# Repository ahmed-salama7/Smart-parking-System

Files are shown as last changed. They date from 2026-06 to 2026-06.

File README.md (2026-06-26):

# Smart Parking System

> An automated parking-management prototype that detects vehicles with FC-51 IR
> sensors at the entrance and exit and controls access through a servo gate,
> driven by a finite-state-machine firmware on an Arduino Uno. Live occupancy is
> shown on an LCD with traffic-light feedback.

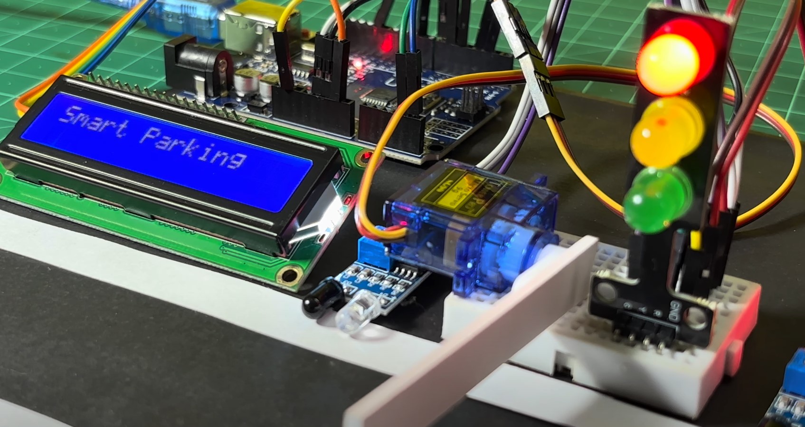
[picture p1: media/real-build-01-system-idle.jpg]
Smart Parking System — real build


---

## Problem

Conventional parking lots give drivers no live information about availability —
you enter, search, and often find the lot full only after wasting time and fuel.
This project demonstrates an automated, low-cost alternative: a system that
tracks occupancy in real time, controls access automatically, and shows drivers
the number of free spaces at a glance.

---

## How It Works

- **Two FC-51 IR sensors** detect vehicles at the entrance and the exit
  (active-LOW digital output — LOW when a car breaks the beam).
- The system **counts cars in and out against a 4-space capacity** — it tracks
  total occupancy rather than sensing each individual bay.
- A **finite state machine** in firmware manages the full gate cycle:
  `idle → car detected → check capacity → open → pass-through → close`.
- An **SG90 servo** drives the entry/exit barrier (0° closed, 90° open).
- A **16×2 I²C LCD** displays live status — free-slot count and OPEN / FULL.
- A **traffic-light LED module** gives instant visual feedback
  (green = enter, yellow = gate moving, red = full).

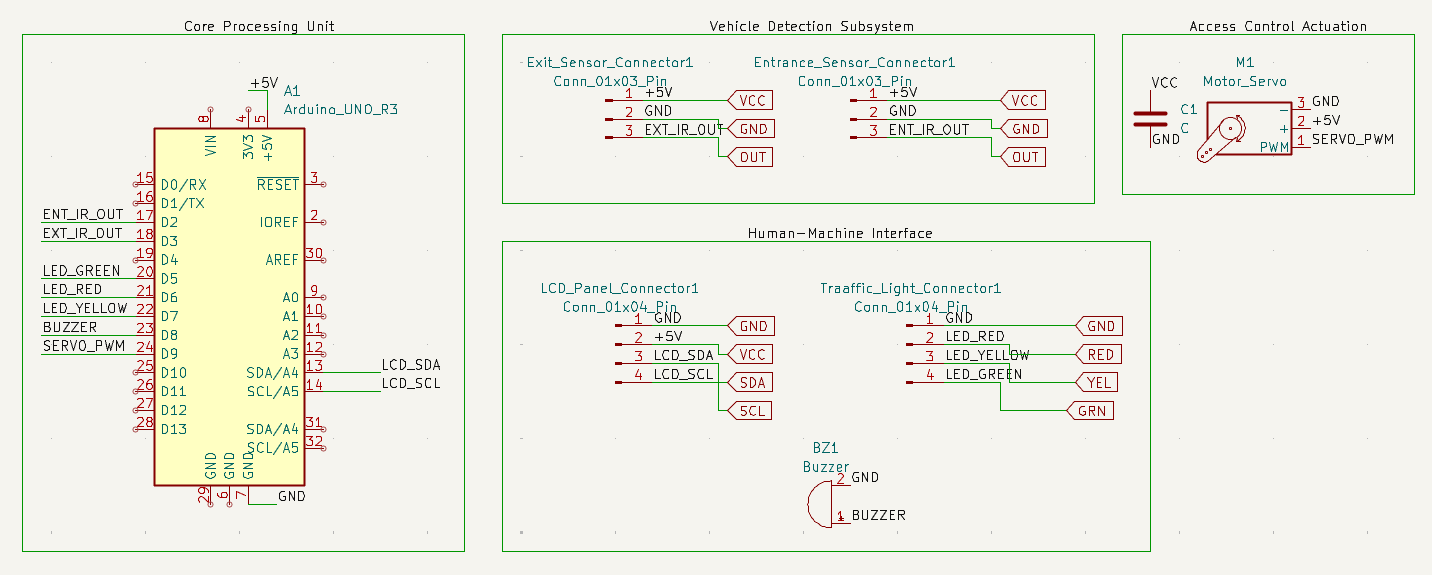
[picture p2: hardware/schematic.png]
System schematic

*System schematic, designed in KiCad.*

---

## Key Components

- **Microcontroller:** Arduino Uno R3 (ATmega328P)
- **Sensors:** FC-51 IR obstacle sensors ×2 (entrance + exit)
- **Actuator:** TowerPro SG90 micro servo (gate barrier)
- **Display:** 16×2 character LCD with PCF8574 I²C backpack
- **Indicators:** Traffic-light LED module (R/Y/G)
- **Custom PCB:** carrier shield designed in KiCad (see [`/hardware`](hardware/))

Full bill of materials: [`docs/SmartParking_BOM.xlsx`](docs/SmartParking_BOM.xlsx).
Engineering write-up: [`docs/DESIGN_NOTES.md`](docs/DESIGN_NOTES.md).

---

## Hardware Design

A custom carrier PCB was designed in KiCad to move the project off breadboard
wiring. The full project files (schematic, board, and project) are in
[`/hardware`](hardware/).

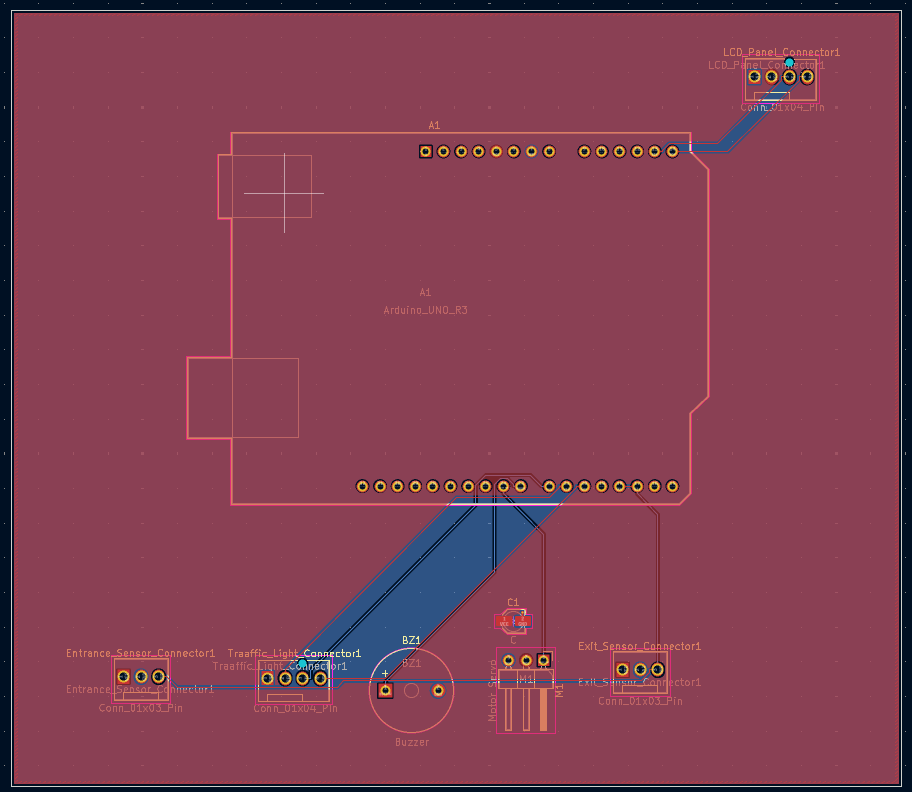
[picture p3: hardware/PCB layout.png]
PCB layout

*Custom PCB layout (KiCad).*

---

## Engineering Notes — From Simulation to Hardware

The control logic was first validated in a **Wokwi simulation**, then ported to
the physical board. That port was the most instructive part of the build:

- **Different sensors in simulation vs hardware.** Wokwi doesn't provide the
  FC-51 IR module, so the simulation uses **HC-SR04 ultrasonic** sensors while
  the real board ([`firmware/arduino_smart_parking_system_fc51.ino`](firmware/arduino_smart_parking_system_fc51.ino))
  uses **FC-51 IR**. The two detect vehicles differently as a result: the
  simulation reads an ultrasonic *distance* and compares it against a threshold,
  whereas the real board reads the FC-51's *digital beam-break* output directly.
- **Debouncing the IR input.** A raw IR module can blip on ambient light or a
  passing hand, so the firmware only accepts a vehicle after several consecutive
  "detected" reads — rejecting single-frame false triggers.
- **A gate safety timeout.** If a vehicle stalls in the beam or a sensor sticks
  on, the gate force-closes after a fixed timeout instead of hanging open and
  freezing the whole system.

---

## The System in Action

The physical prototype running a complete parking cycle — from an empty lot,
through vehicles entering, to a full lot denying access:

| | | |
|:--:|:--:|:--:|
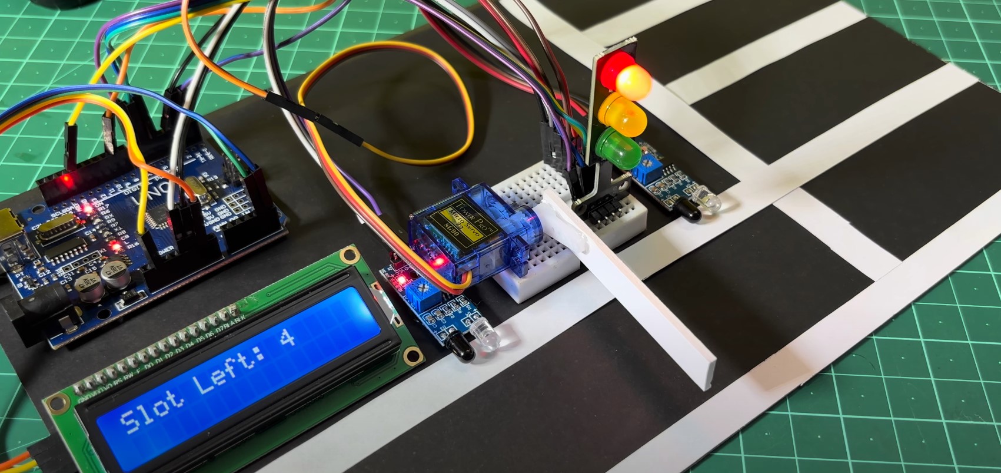
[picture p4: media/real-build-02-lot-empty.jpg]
Lot empty
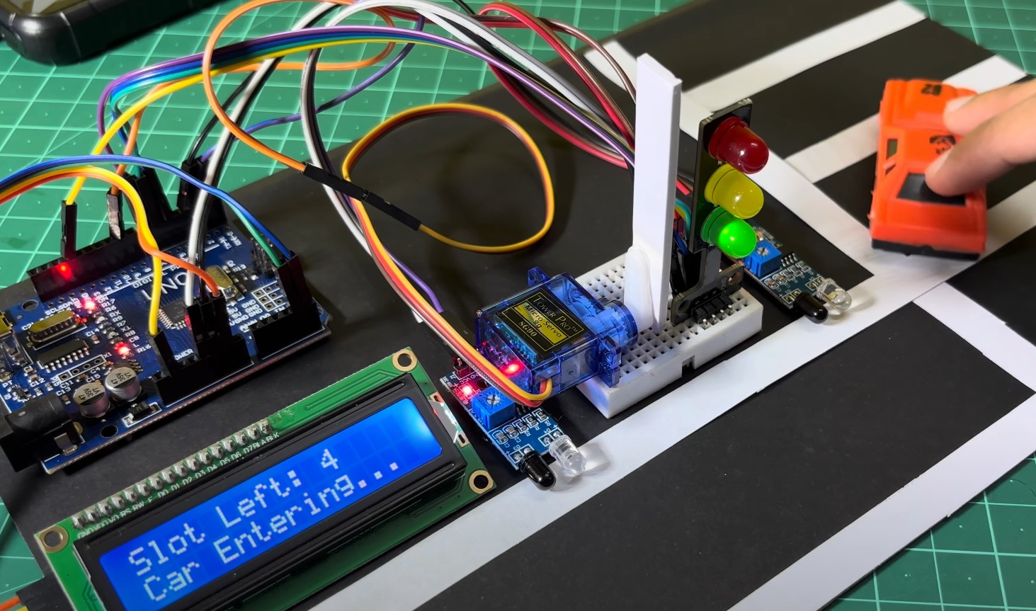
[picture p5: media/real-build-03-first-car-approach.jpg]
First car approaching
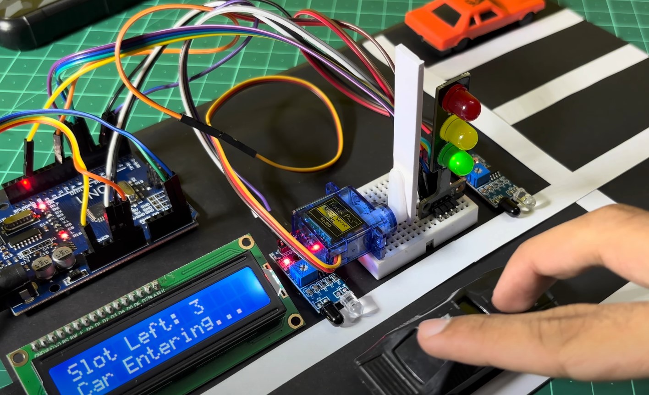
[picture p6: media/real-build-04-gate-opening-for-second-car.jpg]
Gate opening
|  |  |  |
| **Lot empty** — 4 slots free, gate down | **First car approaches**  | **Gate opens** — "Car entering..." |
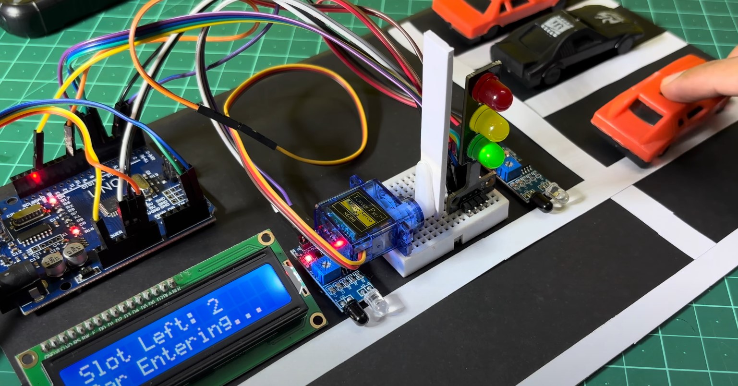
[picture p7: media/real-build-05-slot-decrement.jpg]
Slot decrement
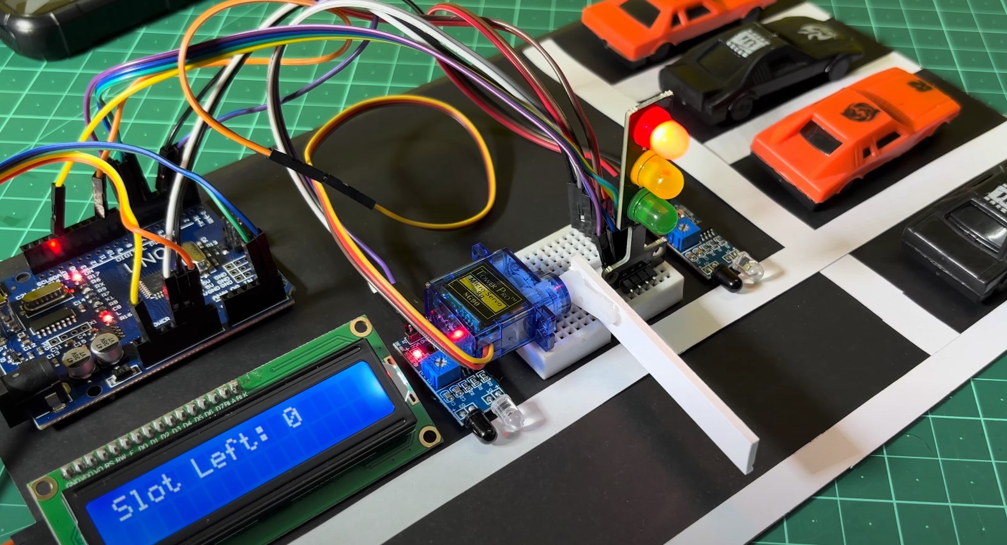
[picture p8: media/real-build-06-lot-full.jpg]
Lot full
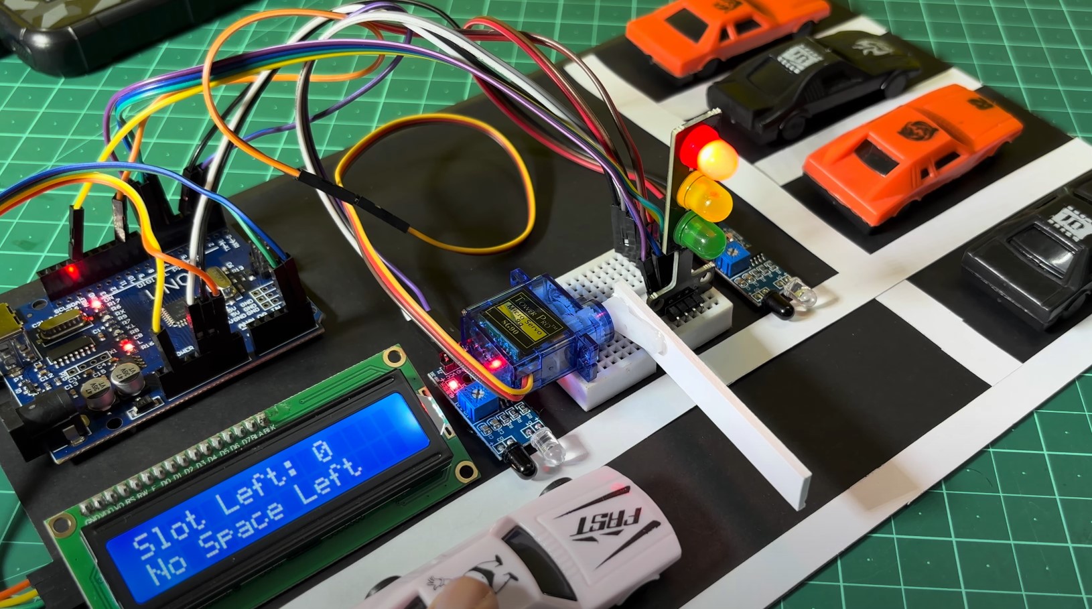
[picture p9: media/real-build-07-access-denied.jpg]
Access denied
|  |  |  |
| **Slot count drops** as cars are admitted | **Lot full** — 0 spaces available | **Access denied** — "No Space Left", red light |

---

## Simulation

The full control logic was validated in a Wokwi simulation before hardware
testing (sensor difference explained in *Engineering Notes* above).

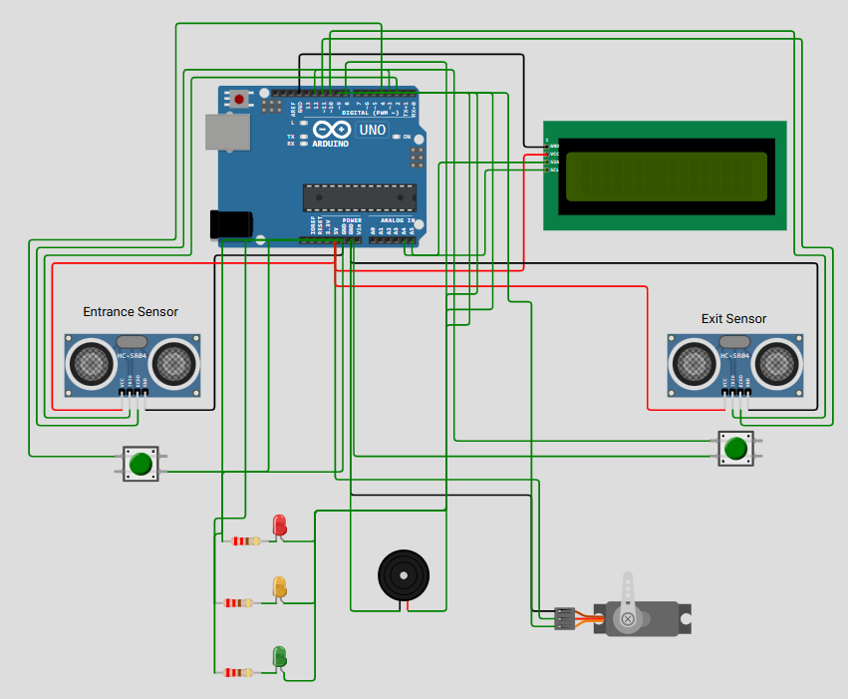
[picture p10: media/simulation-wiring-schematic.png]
Simulation wiring

*Wokwi simulation wiring (uses HC-SR04 in place of the FC-51 modules).*

Simulation demo

[▶️ Watch the full simulation video](media/simulation-behavioral-demo-video.mp4)

---

## Repository Structure

```
Smart-parking-System/
├── firmware/
│   └── arduino_smart_parking_system_fc51.ino   Real board (FC-51 IR)
├── hardware/
│   ├── Smart Parking System.kicad_sch          KiCad schematic
│   ├── Smart Parking System.kicad_pcb          KiCad board layout
│   ├── Smart Parking System.kicad_pro          KiCad project
│   ├── schematic.png                           Schematic export
│   └── PCB layout.png                          PCB layout export
├── docs/
│   ├── DESIGN_NOTES.md                         Engineering write-up
│   └── SmartParking_BOM.xlsx                    Bill of materials
├── media/                                      Real-build photos, sim video/GIF
└── README.md
```

---

## Status

Working hardware prototype, 2026.

<!-- [VERIFY] Optional metric: "Detection accuracy 100% (entrance) / 95% (exit)
over 20 trials each." Keep this ONLY if you actually ran and logged these
trials. If you didn't, delete this comment entirely. -->

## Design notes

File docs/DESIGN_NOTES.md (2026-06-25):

# Design Notes — Smart Parking System

Engineering design documentation for the Smart Parking System: an Arduino-based
parking-management prototype that detects vehicles with IR sensors, controls a
servo gate via a finite-state-machine firmware, and reports live occupancy on an
LCD with traffic-light and buzzer feedback.

---

## 1. Design Goals

The project set out to satisfy four requirements:

1. Detect vehicle presence at the entrance and exit in real time.
2. Automatically open or deny gate access depending on available capacity.
3. Display live parking status to drivers (free slots, OPEN / FULL).
4. Achieve all of the above on a low-cost (~$22) Arduino platform with reliable,
   repeatable operation.

The guiding principle throughout was **reliability over features** — a simpler
system that never miscounts is more valuable than a complex one that occasionally
fails.

---

## 2. System Architecture

The system is organised as a classic three-stage embedded pipeline:

```
INPUT                  PROCESSING                 OUTPUT
─────                  ──────────                 ──────
Entrance IR  ─┐                              ┌─►  Servo gate (SG90)
              ├─►   Arduino Uno (ATmega328P)  ├─►  16×2 LCD (I²C)
Exit IR     ─┘      • Debounced events        ├─►  Traffic LEDs (R/Y/G)
                    • Finite state machine     └─►  Buzzer
                    • Occupancy + capacity
```

The Arduino Uno acts as the edge controller. All modules share a single
regulated 5 V rail and a common ground.

---

## 3. Component Selection & Rationale

| Function | Part chosen | Why this part |
|---|---|---|
| Controller | Arduino Uno R3 (ATmega328P) | Deterministic, instant-on, no OS, ample I/O, lowest cost for the job |
| Vehicle detection | FC-51 IR obstacle sensor ×2 | Clean active-LOW digital output (onboard LM393 comparator), no distance math, cheap, fixed beam path suits a gate |
| Gate actuator | TowerPro SG90 servo | Sufficient torque for a light barrier, simple PWM control, very low cost |
| Display | 16×2 LCD + PCF8574 I²C backpack | I²C cuts pin usage from 16 lines to 2 (SDA/SCL), freeing GPIO |
| Status indicator | Traffic-light LED module | Common-cathode with onboard SMD resistors — drive directly from GPIO, no external parts |
| Audio feedback | Active piezo buzzer module | Simple `tone()` control for entry chime and full-lot alarm |

**Key decision — IR over ultrasonic:** the FC-51 modules output a clean digital
LOW/HIGH, so the microcontroller does no distance calculation, needs no averaging
filter, and has no echo-timeout risk. For a gate, where the detection point is
fixed and known, this is more robust and cheaper than ultrasonic ranging.

---

## 4. Firmware Design

The firmware is written in embedded C++ and structured as an **explicit finite
state machine** rather than ad-hoc conditional logic.

**States:** `IDLE`, `VEHICLE_ENTERING`, `VEHICLE_EXITING`, `LOT_FULL_WARN`.

**Control flow:** the controller idles while monitoring both sensors. On an
entrance trigger it checks capacity — if a slot is free it opens the gate and
increments the count; if the lot is full it denies access with the buzzer and a
"PARKING FULL" message. The exit path is symmetrical and decrements the count.
All paths return to `IDLE` after updating the display and LEDs.

**Three robustness measures were designed in deliberately:**

- **Debounce timer (300 ms).** Recorded with `millis()`, this rejects repeat
  triggers from a single slow-moving vehicle so one car is counted exactly once.
- **`constrain()` guard.** The occupancy count is clamped between 0 and total
  capacity, making it mathematically impossible to under- or over-count
  regardless of sensor behaviour.
- **Mutually-exclusive dispatch (`else-if`).** Entrance and exit events can never
  be processed in the same loop cycle, preventing race conditions.

**Code-quality practices:** all magic numbers are named constants, all LED state
is set through a single `setLEDs()` function (one source of truth), string
literals are stored in flash with the `F()` macro to save SRAM, and serial debug
output is provided throughout for diagnostics.

---

## 5. Engineering Challenge — Power Integrity

This was the most significant problem encountered, and the most instructive.

**Symptom.** When the servo moved to operate the gate, the LCD would glitch
mid-message and the Arduino would occasionally reset.

**Diagnosis.** The SG90 draws a sharp inrush current the instant it starts
moving. On the breadboard — with thin jumper wires and no local energy storage —
that current spike pulled the shared 5 V rail down far enough to brown out the
logic and reset the microcontroller. The fault correlated exactly with gate
movement, which identified the servo as the source.

**Solution.** A **470 µF electrolytic bulk capacitor** placed directly across the
5 V rail next to the servo. The capacitor acts as a local energy reservoir,
supplying the inrush current so the rest of the circuit sees a stable supply.
This was implemented properly on the PCB, alongside a ground pour on both copper
layers and a widened trace to the servo.

**Result.** Power-related glitches dropped from ~6 per 50 gate cycles to 0.

This is the textbook reason decoupling and bulk capacitors exist; encountering it
firsthand turned a theoretical rule into practical understanding.

---

## 6. PCB Design

The breadboard prototype was translated into a custom PCB using KiCad.

- **Form factor:** a two-layer Arduino carrier shield. Because every part is a
  pre-built module, the board is a carrier that breaks each Arduino pin out to a
  labelled connector rather than a component-level board.
- **Connectors:** pluggable headers / screw terminals for every module, so parts
  remain reusable and the board is repairable. None are soldered directly.
- **Power integrity:** ground pour on both layers, a widened 5 V trace to the
  servo, and the 470 µF bulk capacitor positioned at the servo connector.
- **Workflow:** schematic capture → footprint assignment → two-layer routing →
  DRC → 3D render for a final placement check before fabrication.

---

## 7. Validation & Results

Testing was treated as a structured activity with defined trials and recorded
numerical results.

| Metric | Result |
|---|---|
| Entrance sensor detection accuracy | 100% (20/20 trials) |
| Exit sensor detection accuracy | 95% (19/20 trials) |
| Rail glitches before bulk capacitor | 6 per 50 gate cycles |
| Rail glitches after bulk capacitor | 0 per 50 gate cycles |
| Full entry-cycle time | ~2.5 s (dominated by vehicle pass-through) |
| Total BOM cost (required parts) | ~$21.70 |

The exit sensor's 95% reflects occasional beam interference from the mounting
angle, correctable with a small physical adjustment.

---

## 8. Known Limitations & Future Work

**Current limitations:**

- Single-gate, single-zone prototype.
- Blocking `delay()` / wait-for-clear logic means the system focuses on one event
  at a time (acceptable for one gate, but not ideal at scale).
- The gate holds open indefinitely if a vehicle stalls in the beam — a safe
  failure mode, but not a timed one.

**Future work:**

- **IoT upgrade:** add an ESP8266 to stream live occupancy over Wi-Fi to an MQTT
  broker, with a mobile app showing drivers availability before arrival. This is
  a pure addition — no change to the existing firmware or hardware.
- **RFID access control** for authenticated entry.
- **Multi-level scaling:** replicate the state machine per gate, reporting to a
  central controller.
- **Fully non-blocking firmware:** replace remaining `delay()` calls with a
  `millis()`-based scheduler so both sensors stay responsive during gate motion.

---

## 9. Notes on the Simulation

The physical build used FC-51 IR sensors. The Wokwi simulation used **HC-SR04
ultrasonic sensors instead**, because the FC-51 module is not available in Wokwi.
This introduced fluctuating distance readings in simulation, handled with a
five-sample averaging filter and a validity check discarding readings above
200 cm. This filtering is a **simulation-only** concern — the real FC-51 modules
output a clean digital signal that needs no filtering. The simulation was used to
validate the control logic before hardware testing and as a reproducible,
shareable demonstration of the system's behaviour.

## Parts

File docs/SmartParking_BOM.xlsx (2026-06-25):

Smart Parking System — Bill of Materials
Arduino-based Smart Parking Management System · real-hardware build
Currency: USD ($) · Prices are indicative — replace with your supplier (e.g. Robotistan) quotes before final submission
Item | Category | Component / Part | Key Specification | Interface / Pin | Qty | Unit Price ($) | Line Total ($) | Required | Function / Notes
1 | Core Control | Arduino Uno R3 (ATmega328P) | 8-bit MCU board, 16 MHz, 14 digital I/O, 6 analog in | USB / host | 1 | $8.50 | $8.50 | Yes | Edge controller — runs the state machine, reads sensors, drives all actuators
2 | Input — Sensor | FC-51 IR Obstacle Sensor — Entrance | LM393 comparator, potentiometer-calibrated, active-LOW digital output | D2 (digital in) | 1 | $1.20 | $1.20 | Yes | Detects a vehicle breaking the beam at the entrance lane
3 | Input — Sensor | FC-51 IR Obstacle Sensor — Exit | LM393 comparator, potentiometer-calibrated, active-LOW digital output | D3 (digital in) | 1 | $1.20 | $1.20 | Yes | Detects a vehicle leaving at the exit lane
4 | Output — Actuator | TowerPro SG90 Micro Servo (9g) | Plastic-gear, 0°–90° travel, 4.8–6 V, hardware-PWM control | D9 (PWM) | 1 | $2.50 | $2.50 | Yes | Raises (90°) / lowers (0°) the physical gate arm
5 | Output — Display | 16x2 LCD + PCF8574 I2C Backpack | HD44780 16x2 char, I2C address 0x27, 2-wire interface | A4/SDA, A5/SCL | 1 | $4.00 | $4.00 | Yes | Shows live slot count and OPEN / FULL status
6 | Output — Indicator | Traffic-Light LED Module | Red/Yellow/Green, common cathode, onboard SMD current-limit resistors | D5, D6, D7 | 1 | $2.00 | $2.00 | Yes | Visual parking status (no VCC pin — common cathode)
7 | Output — Audio | Active Piezo Buzzer Module | Active piezo transducer, driven by tone() square wave | D8 (digital) | 1 | $0.80 | $0.80 | Yes | Entry confirmation chime and lot-full alarm
8 | Prototyping | Mini Breadboard (170 tie-points) | Solderless, 170 contact points, self-adhesive base | — | 1 | $1.50 | $1.50 | Yes | Local mounting node for the servo and traffic-light module
9 | Supporting (opt.) | Jumper Wires — Dupont set | M-M / M-F, 2.54 mm, assorted lengths | — | 1 | $2.00 | $2.00 | Optional | Interconnect between the Uno and modules
10 | Supporting (opt.) | USB Cable (A–B) | Standard printer-type cable | USB | 1 | $1.50 | $1.50 | Optional | Firmware upload and power to the Uno
 |  | TOTAL — required items |  |  |  |  | $21.70
 |  | TOTAL — including optional items |  |  |  |  | $25.20
 |  | Distinct line items / total units |  |  |  |  | 10 items / 10 units

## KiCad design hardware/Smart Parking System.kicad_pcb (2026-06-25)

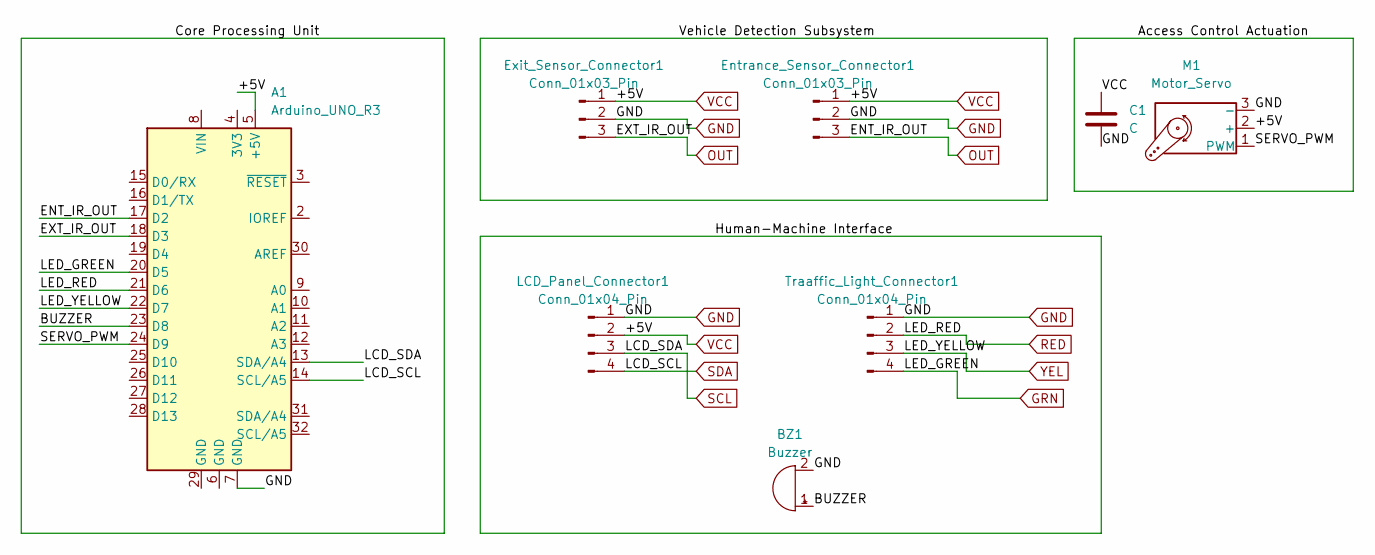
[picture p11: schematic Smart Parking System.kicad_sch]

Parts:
A1: Arduino_UNO_R3
BZ1: Buzzer; Buzzer_12x9.5RM7.6
C1: C; C_Elec_3x5.4
Entrance_Sensor_Connector1: Conn_01x03_Pin; FanPinHeader_1x03_P2.54mm_Vertical
Exit_Sensor_Connector1: Conn_01x03_Pin; FanPinHeader_1x03_P2.54mm_Vertical
LCD_Panel_Connector1: Conn_01x04_Pin; FanPinHeader_1x04_P2.54mm_Vertical
M1: Motor_Servo; PinHeader_1x03_P2.54mm_Horizontal
Traaffic_Light_Connector1: Conn_01x04_Pin; FanPinHeader_1x04_P2.54mm_Vertical

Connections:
/BUZZER: A1.23 (D8), BZ1.1 (+)
/SERVO_PWM: A1.24 (D9), M1.1 (PWM)
GND: A1.7 (GND), BZ1.2 (-), C1.2, Entrance_Sensor_Connector1.2, Exit_Sensor_Connector1.2, LCD_Panel_Connector1.1, M1.3 (-), Traaffic_Light_Connector1.1
GRN: A1.20 (D5), Traaffic_Light_Connector1.4
OUT: A1.17 (D2), A1.18 (D3), Entrance_Sensor_Connector1.3, Exit_Sensor_Connector1.3
RED: A1.21 (D6), Traaffic_Light_Connector1.2
SCL: A1.13 (SDA/A4), LCD_Panel_Connector1.3
SDA: A1.14 (SCL/A5), LCD_Panel_Connector1.4
VCC: A1.5 (+5V), C1.1, Entrance_Sensor_Connector1.1, Exit_Sensor_Connector1.1, LCD_Panel_Connector1.2, M1.2 (+)
YEL: A1.22 (D7), Traaffic_Light_Connector1.3

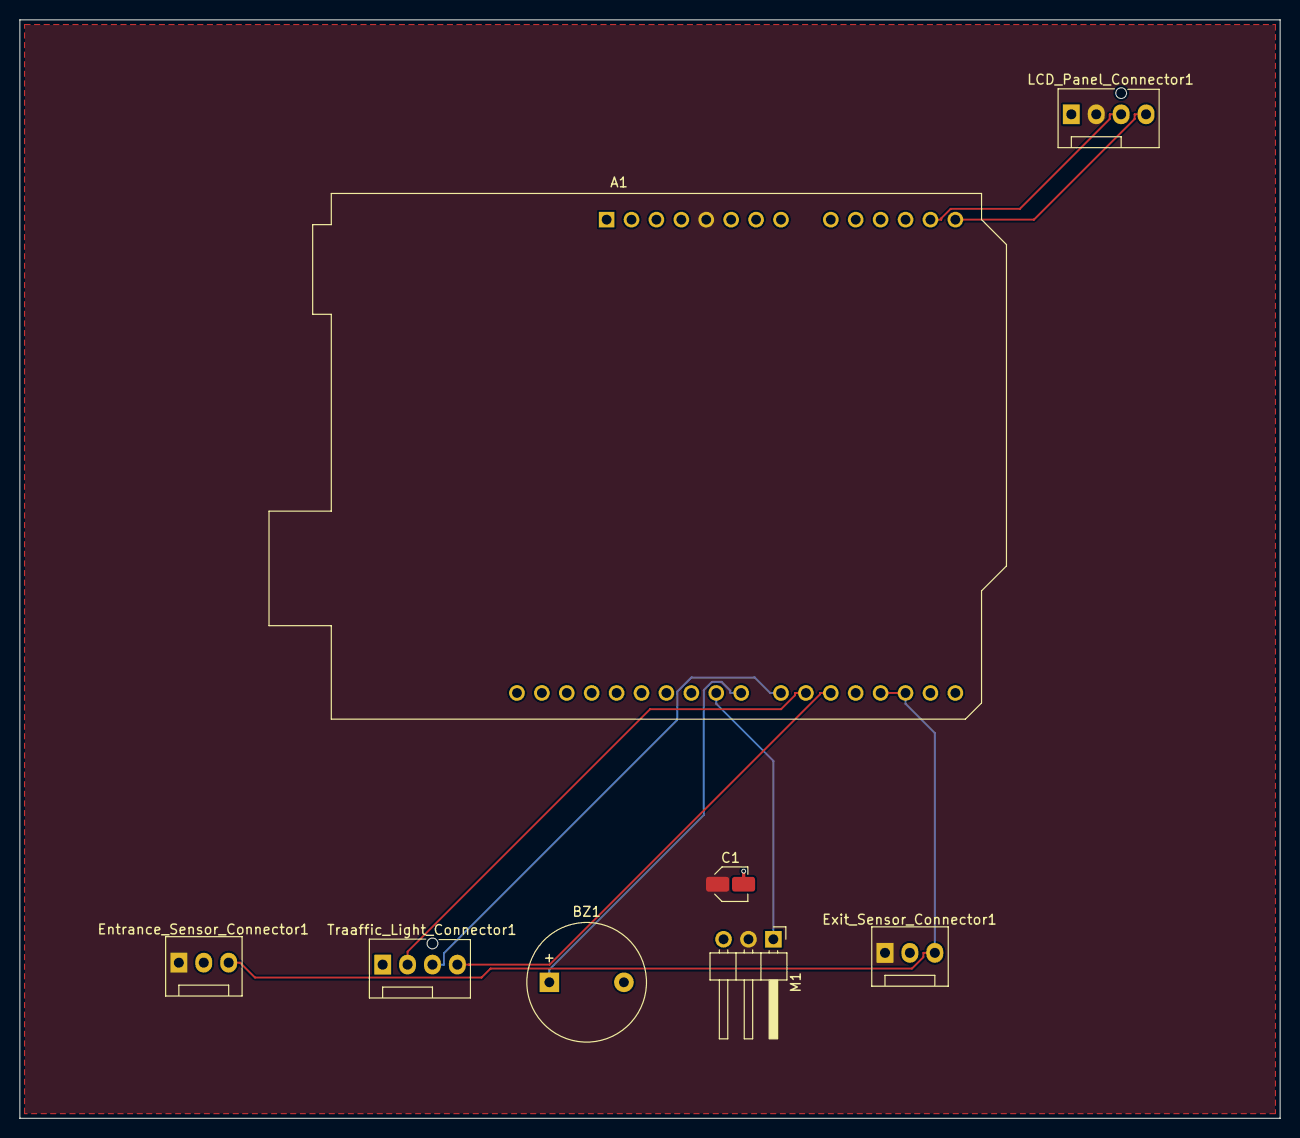
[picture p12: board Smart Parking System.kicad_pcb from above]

Board: 2 copper layers, 128.5 x 112.0 mm, 8 parts (0 on the bottom side), 10 nets.

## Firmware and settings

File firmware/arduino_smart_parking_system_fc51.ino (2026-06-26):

// =============================================================================
//  Smart Parking Management System  —  REAL BOARD (FC-51 IR sensors)
//
//  MCU      : Arduino Uno
//  Sensors  : 2x FC-51 IR obstacle sensors  (entrance + exit, active-LOW)
//  Actuator : SG90 servo                     (entry/exit barrier)
//  Display  : 16x2 I2C LCD
//  Feedback : Green / Red / Yellow LEDs       (traffic-light style)
//
//  This is the firmware for the PHYSICAL prototype. FC-51 modules output a
//  clean digital obstacle signal (LOW when a vehicle breaks the IR beam), so no
//  distance measurement is needed. The Wokwi simulation of this project uses
//  HC-SR04 ultrasonic sensors instead (the FC-51 module isn't available in
//  Wokwi) and lives in firmware/simulation/.
// =============================================================================

#include <Wire.h>
#include <LiquidCrystal_I2C.h>
#include <Servo.h>

// -----------------------------------------------------------------------------
//  Pin map
// -----------------------------------------------------------------------------
const uint8_t ENTRANCE_IR = 2;    // FC-51 OUT — LOW when a vehicle is detected
const uint8_t EXIT_IR     = 3;    // FC-51 OUT — LOW when a vehicle is detected

const uint8_t GREEN_LED   = 5;
const uint8_t RED_LED     = 6;
const uint8_t YELLOW_LED  = 7;
const uint8_t SERVO_PIN   = 9;

// -----------------------------------------------------------------------------
//  Tunable parameters
// -----------------------------------------------------------------------------
const uint8_t  TOTAL_SPACES       = 4;
const uint8_t  CONFIRM_READS      = 4;     // Consecutive "detected" reads needed
const uint8_t  DEBOUNCE_SAMPLE_MS = 8;     // Gap between confirmation samples
const uint16_t GATE_OPEN_HOLD_MS  = 1000;  // Hold after the beam clears
const uint16_t GATE_MAX_OPEN_MS   = 8000;  // Safety: force-close after this
const uint16_t FULL_WARN_MS       = 1500;  // "FULL" message display time
const uint16_t DEBOUNCE_MS        = 1000;  // Min ms between accepted triggers

const uint8_t  GATE_CLOSED_DEG    = 0;
const uint8_t  GATE_OPEN_DEG      = 90;

// FC-51 output polarity: LOW = obstacle present
const uint8_t  VEHICLE_DETECTED   = LOW;

// -----------------------------------------------------------------------------
//  System-state enum — makes the finite state machine explicit
// -----------------------------------------------------------------------------
enum SystemState : uint8_t {
  STATE_IDLE,
  STATE_VEHICLE_ENTERING,
  STATE_VEHICLE_EXITING,
  STATE_LOT_FULL_WARN
};

// -----------------------------------------------------------------------------
//  Globals
// -----------------------------------------------------------------------------
LiquidCrystal_I2C lcd(0x27, 16, 2);   // If the LCD stays blank, try 0x3F
Servo             gateServo;
SystemState       currentState   = STATE_IDLE;
uint8_t           availableSlots = TOTAL_SPACES;

uint32_t          lastEntranceMs = 0;   // Debounce timestamps
uint32_t          lastExitMs     = 0;

// -----------------------------------------------------------------------------
//  setup()
// -----------------------------------------------------------------------------
void setup() {
  Serial.begin(9600);

  pinMode(ENTRANCE_IR, INPUT);
  pinMode(EXIT_IR,     INPUT);

  pinMode(GREEN_LED,  OUTPUT);
  pinMode(RED_LED,    OUTPUT);
  pinMode(YELLOW_LED, OUTPUT);

  gateServo.attach(SERVO_PIN);
  closeGate();

  lcd.init();
  lcd.backlight();

  Serial.println(F("=== Smart Parking System READY (FC-51) ==="));
  updateDisplay();
}

// -----------------------------------------------------------------------------
//  loop()  — poll both sensors, dispatch entry/exit events
// -----------------------------------------------------------------------------
void loop() {
  uint32_t now = millis();

  // --- ENTRANCE ---
  if (vehiclePresent(ENTRANCE_IR) && (now - lastEntranceMs) > DEBOUNCE_MS) {
    lastEntranceMs = now;
    if (availableSlots > 0) handleVehicleEntry();
    else                    handleLotFull();
  }
  // --- EXIT  (else-if prevents simultaneous entry+exit processing) ---
  else if (vehiclePresent(EXIT_IR) && (now - lastExitMs) > DEBOUNCE_MS) {
    lastExitMs = now;
    if (availableSlots < TOTAL_SPACES) handleVehicleExit();
  }
}

// -----------------------------------------------------------------------------
//  Event handlers
// -----------------------------------------------------------------------------
void handleVehicleEntry() {
  currentState = STATE_VEHICLE_ENTERING;
  Serial.print(F("ENTRY  - slots before: ")); Serial.println(availableSlots);

  setLEDs(false, false, true);        // Yellow = gate moving

  lcd.clear();
  lcd.setCursor(0, 0); lcd.print(F("Slots left: ")); lcd.print(availableSlots);
  lcd.setCursor(0, 1); lcd.print(F("Car entering... "));

  openGate();
  waitForClear(ENTRANCE_IR);          // Hold until the car passes the beam
  delay(GATE_OPEN_HOLD_MS);
  closeGate();

  availableSlots = constrain(availableSlots - 1, 0, TOTAL_SPACES);
  Serial.print(F("ENTRY done - slots now: ")); Serial.println(availableSlots);

  currentState = STATE_IDLE;
  updateDisplay();
}

void handleVehicleExit() {
  currentState = STATE_VEHICLE_EXITING;
  Serial.print(F("EXIT   - slots before: ")); Serial.println(availableSlots);

  setLEDs(false, false, true);

  lcd.clear();
  lcd.setCursor(0, 0); lcd.print(F("Vehicle leaving "));
  lcd.setCursor(0, 1); lcd.print(F("Opening gate... "));

  openGate();
  waitForClear(EXIT_IR);
  delay(GATE_OPEN_HOLD_MS);
  closeGate();

  availableSlots = constrain(availableSlots + 1, 0, TOTAL_SPACES);
  Serial.print(F("EXIT done - slots now: ")); Serial.println(availableSlots);

  currentState = STATE_IDLE;
  updateDisplay();
}

void handleLotFull() {
  currentState = STATE_LOT_FULL_WARN;
  Serial.println(F("LOT FULL - entry denied"));

  setLEDs(false, true, false);        // Red only

  lcd.clear();
  lcd.setCursor(0, 0); lcd.print(F("  PARKING FULL  "));
  lcd.setCursor(0, 1); lcd.print(F(" NO SPACE LEFT! "));
  delay(FULL_WARN_MS);

  currentState = STATE_IDLE;
  updateDisplay();
}

// -----------------------------------------------------------------------------
//  Sensor helper — software-debounced read of an FC-51 module
// -----------------------------------------------------------------------------
// Returns true only if the sensor reads "detected" for CONFIRM_READS samples in
// a row. A raw IR module can blip on ambient light or a passing hand; requiring
// several consecutive reads rejects those single-frame false triggers.
bool vehiclePresent(uint8_t irPin) {
  for (uint8_t i = 0; i < CONFIRM_READS; i++) {
    if (digitalRead(irPin) != VEHICLE_DETECTED) return false;
    delay(DEBOUNCE_SAMPLE_MS);
  }
  return true;
}

// Block until the beam is clear again, with a safety timeout so a stalled car
// or a stuck sensor can't hold the gate open and freeze the whole system.
void waitForClear(uint8_t irPin) {
  uint32_t start = millis();
  while (digitalRead(irPin) == VEHICLE_DETECTED) {
    if (millis() - start > GATE_MAX_OPEN_MS) {
      Serial.println(F("WARN: gate-open timeout - forcing close"));
      return;
    }
    delay(50);
  }
}

// -----------------------------------------------------------------------------
//  Gate control
// -----------------------------------------------------------------------------
void openGate()  { gateServo.write(GATE_OPEN_DEG);   }
void closeGate() { gateServo.write(GATE_CLOSED_DEG); }

// -----------------------------------------------------------------------------
//  LED control — single function keeps the LED state consistent
// -----------------------------------------------------------------------------
void setLEDs(bool green, bool red, bool yellow) {
  digitalWrite(GREEN_LED,  green  ? HIGH : LOW);
  digitalWrite(RED_LED,    red    ? HIGH : LOW);
  digitalWrite(YELLOW_LED, yellow ? HIGH : LOW);
}

// -----------------------------------------------------------------------------
//  Display
// -----------------------------------------------------------------------------
void updateDisplay() {
  bool isFull = (availableSlots == 0);

  lcd.clear();
  lcd.setCursor(0, 0);
  lcd.print(F("Slots left: ")); lcd.print(availableSlots);

  lcd.setCursor(0, 1);
  lcd.print(isFull ? F("Status: FULL") : F("Status: OPEN"));

  setLEDs(!isFull, isFull, false);    // Green if open, Red if full

  Serial.print(F("Display updated - "));
  Serial.print(availableSlots);
  Serial.println(isFull ? F(" slots - FULL") : F(" slots - OPEN"));
}
